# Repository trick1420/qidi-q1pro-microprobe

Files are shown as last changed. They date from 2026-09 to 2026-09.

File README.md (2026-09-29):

# Add a BIQU MicroProbe to a QIDI Q1 Pro and keep the nozzle probe

The Q1 Pro ships with two Z sensors. Most MicroProbe guides replace both. This guide
replaces only the one that fails, and keeps the one that makes the printer
self-calibrating.

Tested on a QIDI Q1 Pro running QIDI's Klipper fork, version `25ee65122`
(firmware V4.4.21), on 2026-09-25.

## What you get

| | Standard MicroProbe guides | This guide |
|---|---|---|
| Bed mesh sensor | MicroProbe | MicroProbe |
| Z=0 sensor | MicroProbe, fixed `z_offset` | Nozzle piezo, measured every print |
| Calibrate `z_offset` after a nozzle change | Yes | No |
| Calibrate `z_offset` after changing the probe mount | Yes | No |
| Detects a blob on the nozzle | No | Yes, as a number in the log |

The difference matters because a fixed `z_offset` is a guess that ages. Change the
nozzle, knock the probe, or leave a bead of plastic on the tip, and the first layer
moves with no warning. The piezo measures the real nozzle-to-plate distance before
every print, so those changes correct themselves.

## Who this is for

You need to be comfortable editing Klipper config files over SSH or through the
Fluidd or Mainsail file editor. You do not need to understand Klipper internals.
Every file and line is named.

Back up these files before you start. Copy them somewhere off the printer.

```
~/klipper_config/printer.cfg
~/klipper_config/gcode_macro.cfg
~/klipper_config/Adaptive_Mesh.cfg
```

## How the Q1 Pro measures Z

The printer has two separate sensors, on two separate pins:

| Sensor | Config section | Pin | Job |
|---|---|---|---|
| Piezo, under the bed | `[smart_effector]` | `U_1:PC1` | Finds Z=0 by touching the plate with the nozzle |
| Inductive, on the toolhead | `[qdprobe]` | `!gpio21` | Probes the bed mesh |

QIDI's fork adds two commands, `QIDI_PROBE_PIN_1` and `QIDI_PROBE_PIN_2`, that switch
which sensor Klipper reads. `PIN_1` selects `[smart_effector]`. `PIN_2` selects
`[qdprobe]`.

`[qdprobe]` depends on a probe object that `[smart_effector]` creates. The two sections
work as a pair. Neither works alone.

Every print runs this sequence:

1. `G28` homes Z roughly, against whichever sensor is selected.
2. `get_zoffset` selects the piezo, touches the plate with the nozzle five times, and
   declares that contact point to be Z = -0.07.
3. `G29` selects the inductive sensor and probes the bed mesh.

Step 2 is what makes the printer self-calibrating. Step 3 is the one that fails, because
an inductive sensor measures the metal under the plate rather than the surface the
plastic lands on.

## Why the usual approach fails

Most guides delete both sections and add a single `[probe]` section for the MicroProbe.
That removes the piezo, so `get_zoffset` no longer exists and Z=0 comes from a fixed
`z_offset` that you calibrate by hand.

On the test machine, hand calibration with the paper method produced `1.530`. The piezo
later measured the same distance as `1.743`. The error of `0.213 mm` put Z=0 almost
double the intended distance above the plate, which ruined every first layer until the
piezo came back.

The single-probe approach has two more problems on this fork:

- `SAVE_CONFIG` does not persist `[probe] z_offset`. Three calibrations wrote `0.000`
  every time. You have to set the value by hand and delete the auto-generated block.
- `G29` normalizes the mesh with `save_meshoffset` and `set_meshoffset`, which assume
  `z_offset` is near zero. Give `[probe]` a real value and the mesh gets corrected twice,
  which drives the nozzle into the plate.

Keeping the piezo avoids all of this. There is nothing to calibrate and nothing to
persist.

## Step 1: wire the probe

Connect the MicroProbe signal wire to the **existing inductive probe connector** on the
toolhead. That connector is `gpio21`. Leave the piezo wiring alone; it runs to the main
board on a different pin and this conversion never touches it.

Connect the MicroProbe control wire to `gpio11`. QIDI's config declares a second hotend
heatsink fan on that pin, as `[heater_fan hotend_fan2]`, but a stock Q1 Pro has only one
heatsink fan fitted. The pin drives nothing, so it is free.

If you added a second hotend fan yourself, `gpio11` is already in use. Find another free
pin on the toolhead board. Do not take the pin from a fan that exists, or you lose half
your hotend cooling and the nozzle jams partway through long prints.

## Step 2: edit printer.cfg

### Replace the probe sections

Find `[qdprobe]` in `~/klipper_config/printer.cfg`. Replace the `[smart_effector]` and
`[qdprobe]` sections with these. Keep everything else in the file as it is.

```ini
[smart_effector]
pin: U_1:PC1
recovery_time: 0
x_offset: 24
y_offset: 10
z_offset: 0.000001
speed: 5
lift_speed: 5
probe_accel: 50
samples: 2
samples_result: submaxmin
sample_retract_dist: 5.0
samples_tolerance: 0.05
samples_tolerance_retries: 5

[qdprobe]
pin: ^!gpio21
z_offset: 0.000001
activate_gcode:
    probe_deploy
    G4 P500
deactivate_gcode:
    probe_stow
deactivate_on_each_sample: false
```

Three changes from the QIDI originals:

- **`x_offset` and `y_offset` change from `17.6` and `4.4` to `24` and `10`.** These
  values live on `[smart_effector]`, but Klipper applies them to whichever sensor is
  active. Only the MicroProbe probes the mesh, so they must be the MicroProbe's offsets.
  Measure your own mount rather than copying these.
- **`[qdprobe] pin` gains a `^`.** The MicroProbe needs the internal pull-up resistor
  that the inductive sensor did not.
- **`[qdprobe]` gains `activate_gcode` and `deactivate_gcode`.** These deploy and retract
  the pin around each probing run. The original QIDI sensors had no moving parts and
  needed neither.

Leave `z_offset: 0.000001` on both sections. That value is deliberate. The piezo sets the
real zero at print time, so Klipper must not apply an offset of its own.

### Remove the unused fan section

Find `[heater_fan hotend_fan2]` in `printer.cfg` and delete it. It claims `gpio11`, and
Klipper refuses to start if two sections claim the same pin.

Skip this step if you fitted a second hotend fan and chose a different pin in step 1.

### Add the control pin

Add this section anywhere in `printer.cfg`:

```ini
[output_pin probe_enable]
pin: gpio11
value: 1
```

`value: 1` means the pin starts in the retracted position. The pin must be retracted
when the piezo probes, or the pin touches the plate before the nozzle does.

### Check the Z endstop

Find `[stepper_z]` and confirm that `position_endstop` is present and not commented out.
Klipper refuses to start without it.

**Keep whatever value your machine already has. Do not copy one from this guide.** The
value differs between firmware versions: `0` on the 2023 release, `-0.2` on the 2025 one,
and `-0.23` on the test machine after an unrelated earlier edit.

Any of them works, because the setting only defines the Z frame between `G28` and
`get_zoffset`, and `get_zoffset` replaces that frame with a real measurement moments
later.

Some MicroProbe guides tell you to comment this line out. That is correct for a single
`[probe]` section and wrong here.

## Step 3: add the deploy macros

Add these to `~/klipper_config/gcode_macro.cfg`:

```ini
[gcode_macro probe_deploy]
gcode:
    SET_PIN PIN=probe_enable VALUE=0

[gcode_macro probe_stow]
gcode:
    SET_PIN PIN=probe_enable VALUE=1
```

Check the direction before you print. Run `probe_deploy` and watch the pin extend, then
`probe_stow` and watch it retract. If the pin moves the wrong way, swap the two `VALUE`
numbers.

## Step 4: leave the QIDI macros alone

Do not modify `PRINT_START`, `homing_override`, `G29`, `get_zoffset`, `set_zoffset`,
`save_zoffset`, `move_subzoffset`, or `test_zoffset`. They work unchanged. They call
`QIDI_PROBE_PIN_1` and `QIDI_PROBE_PIN_2`, which still exist because `[qdprobe]` is still
there.

If a guide told you to delete or comment out any of those macros, restore them from your
backup.

One optional change removes a duplicate homing cycle. `PRINT_START` calls `G28`, and
`G29` then calls `G28` again. To home once per print and still allow `G29` on its own,
wrap the call inside `G29`:

```ini
{% if 'xyz' not in printer.toolhead.homed_axes %}
    G28
{% endif %}
```

## Step 5: adjust the nozzle wipe

`CLEAR_NOZZLE` in `gcode_macro.cfg` wipes the nozzle by moving it left and right across
a brush. The stock travel reaches `X65`, which collides with the MicroProbe.

The factory macro cleans in three phases: fast shallow passes at `X85`, then **nine slow
deep passes to `X65` at `F500`**, then fast passes again. The slow deep passes are what
actually scrub the nozzle. Everything else is a wipe.

`X65` is where the MicroProbe collides, so the deep scrub has to be shortened rather than
removed. Find your own limit by stepping in with the probe stowed:

```
G28
probe_stow
G90
G1 Z35 F900
G1 X97 F15000
G1 Y243 F15000
G1 Y254 F800
G1 X80 F1000
G1 X77 F1000
G1 X74 F1000
```

Stop when the probe is close to the wiper assembly. The test machine reaches **X73**.
Change the `X65` in the deep-scrub passes to your number and leave the rest of the macro
alone.

**Losing that deep scrub is the real cost of this conversion.** Delete it instead of
shortening it, as I did at first, and ooze bends over on the tip instead of shearing off —
no amount of temperature tuning replaces it.

## Step 6: set the mount height

The MicroProbe pin has a fixed travel. On the test machine that travel is `2.36 mm`, and
it divides between two things that both matter:

```
deployed reach + stowed clearance = pin travel
```

- **Deployed reach** is how far the pin hangs below the nozzle when extended. It must
  exceed anything stuck to the nozzle tip, or the nozzle reaches the plate first and the
  probe never fires.
- **Stowed clearance** is how far the pin sits above the nozzle when retracted. It must
  exceed the height of anything already printed, or the pin catches on the part.

Aim for at least `1.0 mm` deployed and at least `0.6 mm` stowed. The final mount on the
test machine measures:

```
deployed reach     1.391 mm
stowed clearance   0.85 mm
pin travel         2.24 mm
```

`stl/microprobe-mount-v6.stl` is that mount. Treat it as a starting point rather than a
drop-in: nozzle length and how far the probe body seats in its clamp both move the result,
and on the test machine reseating the same bracket shifted the reach by 0.14 mm.

Raising the probe in its mount converts deployed reach into stowed clearance, one
millimeter for one millimeter. If your mount clamps the probe body, set the height there
rather than by redesigning the bracket. Clamp position moves the result more than
bracket geometry does.

## Step 7: verify

Run each step and check the result before moving on.

1. **Restart Klipper.** It must report ready with no warnings.

2. **Confirm the switching commands exist.** Send `QIDI_PROBE_PIN_2`, then
   `QIDI_PROBE_PIN_1`. Both return silently. `Unknown command` means `[qdprobe]` did not
   load.

3. **Home the printer.** Send `G28` and watch the pin. It deploys, probes, and retracts.
   Only the MicroProbe runs here.

4. **Measure the nozzle zero.** Heat the bed to 70°C and the nozzle to 150°C, then send
   `get_zoffset`. Stand at the machine. The nozzle descends and touches the plate five
   times. Read the `Result is z=` line in the console.

   That number is the MicroProbe's standoff, measured by the nozzle. Record it. On the
   test machine it is `-1.601`. Five samples should agree within about `0.01 mm`.

5. **Check Z=0 against a gauge block.** Put a gauge block of known height on the plate at
   the centre, then send `G1 X120 Y120 F6000` and `G1 Z<block height> F300`. The nozzle
   touches the top of the block.

   This is the single most valuable check in the process. A feeler gauge tells you how a
   gap feels; a gauge block tells you whether the machine's idea of Z=0 matches the plate
   surface, against a precision reference. On the test machine a 40 mm block confirmed it
   to within a hundredth of a millimetre.

   `get_zoffset` declares the nozzle contact point as `-0.07`. That value compensates for
   how far the nozzle presses into the plate before the piezo registers force, so **Z=0
   lands on the plate surface**, not above it.

6. **Check the stowed clearance.** Send `probe_stow`, return to `Z0`, and slide feeler
   gauges under the **pin**. Subtract `0.07` from whatever fits.

7. **Print something small** and look at the first layer.

After this, the `Result is z=` value appears in `klippy.log` on every print. Watch it. A
drop of more than about `0.1 mm` means something is on the nozzle tip.

## Optional: guard against a bad mesh

An inductive or mechanical probe can misfire and produce a mesh that drives the nozzle
into the plate or lifts it clear of it. On the test machine, one misfire produced a mesh
that lifted the nozzle `0.954 mm` and wasted seven meters of filament before anyone
noticed.

A guard macro reads the mesh after `G29`, compares it against limits, and stops the print
if the numbers are implausible. A healthy mesh on this machine has a range of `0.03` to
`0.17 mm`. The broken one had a range of `1.175 mm`, so the two are easy to tell apart.

See `mesh_guard.cfg` in this repository. Add `[include mesh_guard.cfg]` to `printer.cfg`
above the `#*# <---------------------- SAVE_CONFIG ---------------------->` line, then
add `VALIDATE_MESH` to `PRINT_START` immediately after `G29`.

Anything below that `SAVE_CONFIG` line gets rewritten automatically, and this printer
rewrites it on every print. Config you put there disappears.

## Level the bed with Z_TILT_ADJUST

The Q1 Pro drives its two Z motors independently, so Klipper can correct a left-to-right
tilt mechanically instead of leaving it to the mesh.

```
G28
Z_TILT_ADJUST
```

The stock `[z_tilt] points` work unchanged. `z_tilt` does **not** apply the probe's XY
offsets — unlike `bed_mesh`, it treats `points` as toolhead positions — so the 24 mm
offset doesn't put them out of reach.

On the test machine this found a **0.1 mm tilt across 215 mm** and converged to 0.008 in
one retry. Run `G29` afterwards; levelling changes the bed plane and any existing mesh is
stale.

Once it converges reliably, add it to `PRINT_START` between homing and the clean, so the
mesh is built on a levelled bed:

```
    G28
    Z_TILT_ADJUST
    CLEAR_NOZZLE HOTEND={hotendtemp}
    G29
    VALIDATE_MESH
```

Both motors sit at the same Y, so this corrects left-right tilt only. Front-to-back tilt
stays the mesh's job.

## Optional: fix the purge line

**Check which prime line you actually have first.** QIDI Studio and OrcaSlicer profiles
often draw their own in `machine_start_gcode`, in which case KAMP's `LINE_PURGE` never
runs and none of the settings below do anything. Search your sliced file for
`machine_start_gcode` and see whether it contains `G1 X... E...` moves.

If KAMP does draw your purge: it probes only the area your part occupies, and it draws the
purge line outside that area. The purge therefore prints on ground the printer never
measured, which makes it the least reliable line of the print.

In `~/klipper_config/Adaptive_Mesh.cfg`:

| Line | Setting | Change to |
|---|---|---|
| 24 | `variable_margin_enable` | `True` |
| 25 | `variable_margin_size` | `15` |
| 168 | `variable_distance_to_object_y` | `5` |

The mesh then extends 15 mm past the part, and the purge line moves to 5 mm from it. The
purge lands on measured ground with 10 mm to spare.

Both of the first two settings are required. Line 62 of the same file forces
`margin_size` to `0` whenever `margin_enable` is `False`.

## Troubleshooting

**`Unknown command: QIDI_PROBE_PIN_1`**
`[qdprobe]` is missing or failed to load. Both `[smart_effector]` and `[qdprobe]` must be
present. Neither works alone.

**`Option 'position_endstop' in section 'stepper_z' must be specified`**
Uncomment `position_endstop: -0.23` in `[stepper_z]`.

**`File contains parsing errors`, every line listed**
Your editor indented the pasted config. Klipper requires option lines to start at column
zero. Only the lines inside `activate_gcode` and `deactivate_gcode` are indented.

**The mesh comes out around -1.5 at every point**
`z_offset` has a real value instead of `0.000001`, so the mesh is corrected twice. Set
both `z_offset` values back to `0.000001`.

**The nozzle never reaches the plate during `get_zoffset`**
The pin is deployed when it should be stowed. Check `probe_deploy` and `probe_stow`
directions, and confirm `[output_pin probe_enable]` has `value: 1`.

**`PROBE_CALIBRATE` returns a negative number**
Something below the nozzle touched first: a deployed pin, or a blob of plastic. You do
not need `PROBE_CALIBRATE` with this setup. The piezo replaces it.

**`sudo systemctl` is not permitted**
QIDI blocks `systemctl` in the sudoers file. Restart services through Moonraker instead,
at **Machine > Services** in Fluidd. Moonraker can restart `klipper`, `moonraker`,
`klipper_mcu`, and `webcamd`.

## Reference

Working configuration from the test machine is in `config-backups/`. `gcode_macro-CHANGES.md`
records every change against the stock files, with the reason for each.

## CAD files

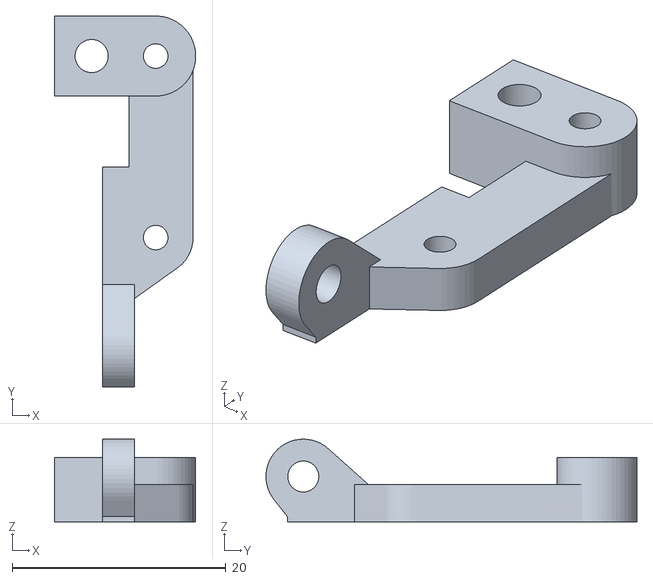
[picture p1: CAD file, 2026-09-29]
stl/microprobe-mount-v6.stl
13.3 x 34.7 x 7.75

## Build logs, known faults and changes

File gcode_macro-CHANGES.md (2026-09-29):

# Change reference

Every change from the stock QIDI Q1 Pro configuration, and the reason for each. The
`README.md` file explains how to make these changes. This file records what they are, so
you can compare against your own machine or undo one of them.

Baseline is the configuration as QIDI shipped it, captured on 2026-09-19 before the
MicroProbe conversion. Current state is 2026-09-25.

Stock and pre-conversion copies of every file are in `config-backups/`.

## printer.cfg

### `[smart_effector]` — the piezo sensor

| Setting | Stock | Now | Why |
|---|---|---|---|
| `x_offset` | `17.6` | `24` | Klipper applies one pair of offsets to whichever sensor is active. Only the MicroProbe probes the mesh, so these must be its offsets. Measure your own mount. |
| `y_offset` | `4.4` | `10` | Same reason. |

`pin: U_1:PC1` and `z_offset: 0.000001` do not change. The piezo wiring is untouched by
this conversion.

### `[qdprobe]` — now the MicroProbe

| Setting | Stock | Now | Why |
|---|---|---|---|
| `pin` | `!gpio21` | `^!gpio21` | The MicroProbe needs the internal pull-up resistor. The inductive sensor did not. |
| `activate_gcode` | absent | `probe_deploy` then `G4 P500` | Extends the pin before probing. The stock sensors had no moving parts. |
| `deactivate_gcode` | absent | `probe_stow` | Retracts the pin afterwards. |
| `deactivate_on_each_sample` | absent | `false` | Deploys once per probing run instead of once per sample. |

`z_offset: 0.000001` does not change, and must not. `[qdprobe]` and `[smart_effector]`
share one probe object, so a real value here gets applied twice and drives the nozzle
into the plate.

### `[heater_fan hotend_fan2]` — removed

Stock declares a second hotend heatsink fan on `gpio11`. A stock Q1 Pro has only one
heatsink fan fitted, so the section drives nothing. Removing it frees `gpio11` for the
MicroProbe control pin, and Klipper refuses to start if two sections claim one pin.

If you added a second hotend fan yourself, keep this section and pick a different pin for
`probe_enable`.

### `[output_pin probe_enable]` — new

```ini
[output_pin probe_enable]
pin: gpio11
value: 1
```

Controls the MicroProbe pin. `value: 1` starts the pin retracted, which the piezo needs.

### `[bed_mesh]`

`vibrate_gcode: Z_DOUDONG` is commented out. `Z_DOUDONG` conditions the piezo sensor
before it measures. The MicroProbe probes the mesh and does not need it.

### `[stepper_z]`

`position_endstop` changed from `-0.2` to `-0.23` on the test machine, by an earlier edit
unrelated to this conversion. The value differs between firmware versions and has no
effect on printing: it sets the Z frame between `G28` and `get_zoffset`, and
`get_zoffset` overwrites that frame a moment later. Keep whatever your machine has.
Klipper refuses to start if the line is missing.

### Includes

`[include mesh_guard.cfg]` added, above the `#*# SAVE_CONFIG` marker. Anything below that
marker is rewritten automatically, on every print.

## gcode_macro.cfg

### New macros

```ini
[gcode_macro probe_deploy]
gcode:
    SET_PIN PIN=probe_enable VALUE=0

[gcode_macro probe_stow]
gcode:
    SET_PIN PIN=probe_enable VALUE=1
```

Swap the two `VALUE` numbers if your pin moves the wrong way.

### `CLEAR_NOZZLE`

| Change | Why |
|---|---|
| Wipe travel `X85` and `X65` becomes `X77` | `X65` collides with the MicroProbe |
| Purge cut from `80 mm` to `30 mm` | Enough to clear ooze on a nozzle that is already clean |
| `G92 E0` then `G1 E-2 F1800` after the purge | Relieves melt-zone pressure. Without it, PETG oozes after the wipe and forms a curl on the tip. |
| `G4 P5000` before the first wipe | Lets the purge blob set so it snaps off rather than smearing |
| First wipe at `180 °C`, second wipe at `140 °C` | Stock waits only for a `20 °C` drop, so it wipes at `230 °C` while PETG still flows, then oozes on the way down with nothing to catch it. The second pass removes that ooze. |

`CLEAR_NOZZLE_PLR` gets the same treatment and an `M107` at the end. Stock leaves the
part fan at full. It runs only when you resume after a power cut.

### `PRINT_START`

Restructured. `CLEAR_NOZZLE` runs before `G29` rather than after `M109`, so the nozzle
cools during meshing instead of making you wait. `VALIDATE_MESH` runs immediately after
`G29`. An optional `SOAK` parameter adds a bed soak in seconds.

### `G29`

The `G28` call is now conditional:

```ini
{% if 'xyz' not in printer.toolhead.homed_axes %}
    G28
{% endif %}
```

`PRINT_START` already homes, so stock homes twice per print. The condition removes the
duplicate and still lets you run `G29` on its own.

### Unchanged

`get_zoffset`, `move_subzoffset`, `set_zoffset`, `save_zoffset`, `test_zoffset`,
`homing_override`, `set_meshoffset`, `save_meshoffset`, and `Z_DOUDONG` are all stock.

Do not delete them. They are the piezo measurement path, and they work unmodified because
`[qdprobe]` still provides `QIDI_PROBE_PIN_1` and `QIDI_PROBE_PIN_2`.

## Adaptive_Mesh.cfg

| Line | Setting | Stock | Now |
|---|---|---|---|
| 24 | `variable_margin_enable` | `False` | `True` |
| 25 | `variable_margin_size` | `5` | `15` |
| 168 | `variable_distance_to_object_y` | `10` | `5` |

KAMP probes only the area your part occupies and draws the purge line outside it, so the
purge prints on ground the printer never measured. These three settings extend the mesh
15 mm past the part and move the purge to 5 mm from it.

Both of the first two are required. Line 62 forces `margin_size` to `0` whenever
`margin_enable` is `False`.

## Z tilt

`Z_TILT_ADJUST` works unchanged and is worth enabling. The stock `[z_tilt] points` need no
edit: `z_tilt` does not apply the probe's XY offsets, unlike `bed_mesh`, so it treats them
as toolhead positions and the 24 mm offset is irrelevant.

On the test machine it found a 0.1 mm left-to-right tilt across 215 mm and converged to
0.008 in one retry. Add it to `PRINT_START` between `G28` and `CLEAR_NOZZLE`.

`[bed_screws]` and `[screws_tilt_adjust]` stay unused. `screws_tilt_adjust` does apply
probe offsets, which puts its front-left screw out of reach, and with `z_tilt` working and
a mesh range under 0.09 there is nothing for manual screw levelling to fix.

## New files

`mesh_guard.cfg` reads the bed mesh after `G29` and stops the print if the numbers are
implausible. A healthy mesh on this machine has a range of `0.03` to `0.17 mm`. One probe
misfire produced a range of `1.175 mm` and a correction that lifted the nozzle `0.954 mm`
off the plate.

Default limits are range `0.80`, peak `0.60`, and step `0.25 mm`. A full-bed mesh
legitimately reaches a peak of about `0.45`, so do not tighten these below `0.5`.

## Measured values from the test machine

Your numbers will differ. These show what a healthy result looks like.

| Value | Reading | Where it comes from |
|---|---|---|
| MicroProbe standoff | `1.391 mm` | `Result is z=` from `get_zoffset`, every print |
| Stowed pin clearance | `0.85 mm` | Feeler gauge under the stowed pin |
| Pin travel | `2.24 mm` | Standoff plus clearance |
| Z=0 accuracy | confirmed | 40 mm gauge block, nozzle touches at `G1 Z40` |
| Bed mesh range | `0.059-0.088 mm` | `MESH CHECK` console line |
| Piezo sample spread | `0.002 mm` | Last four of five samples per run |
| Probe repeatability | `0.005 mm` | `PROBE_ACCURACY`, steady state after two settling probes |

Watch the standoff. It is measured on every print and written to `klippy.log`. A drop of
more than about `0.1 mm` means something is on the nozzle tip.

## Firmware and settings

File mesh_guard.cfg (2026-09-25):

#####################################################################
#  MESH GUARD  -  abort the print if the bed mesh looks implausible
#####################################################################
#
#  WHY THIS EXISTS
#  ---------------
#  On 2026-09-19 at 14:48 the non-contact probe (QIDI_PROBE_PIN_2)
#  misfired during G29. The zero-reference probe returned 2.201
#  instead of its normal ~3.38, and the resulting mesh told the
#  printer to lift the nozzle by up to +0.954 mm across the part.
#  It then extruded 6983 mm of PETG into open air for 66 minutes.
#
#  A broken mesh is trivially distinguishable from a good one:
#
#     time    range   peak    max step    result
#     00:21   0.030   0.023     ~0.02     good
#     00:51   0.157   0.138     ~0.05     good
#     09:44   0.168   0.133     ~0.05     good
#     10:23   0.098   0.089     ~0.04     good
#     17:18   0.135   0.145     ~0.05     good
#     14:48   1.175   0.954      0.62     BROKEN
#
#  The factory full-bed [bed_mesh default] profile reaches
#  range 0.533 / peak 0.449 / step 0.155, so the limits below are
#  set above that to avoid false aborts on whole-plate prints,
#  while still leaving better than 2x margin under the broken run.
#
#  Tighten them once you have a baseline - every run prints its
#  numbers to the console, so after a week you will know your real
#  spread. Adjust live without restarting:
#
#     SET_GCODE_VARIABLE MACRO=VALIDATE_MESH VARIABLE=max_range VALUE=0.5
#
#
#  INSTALL
#  -------
#  1. Back up printer.cfg first:
#       cp ~/klipper_config/printer.cfg ~/klipper_config/printer.cfg.bak
#
#  2. Keep this as its own file and pull it in from printer.cfg:
#       [include mesh_guard.cfg]
#     Better than pasting the macros inline, because this machine runs
#     SAVE_CONFIG on every print and anything living below the
#       #*# <---------------------- SAVE_CONFIG ---------------------->
#     marker gets rewritten. Note the INCLUDE LINE ITSELF still has to
#     sit above that marker or it will be wiped on the next save.
#
#  3. In [gcode_macro PRINT_START], add VALIDATE_MESH directly after
#     G29 so it runs before the hotend comes up to print temperature:
#
#         G28
#         CLEAR_NOZZLE HOTEND={hotendtemp}
#         M190 S{bedtemp}
#         G29
#         VALIDATE_MESH          <-- add this line
#         G0 Z50 F600
#         ...
#
#  4. RESTART, then run a print and confirm you see the
#     "MESH CHECK" line in the console.
#
#  TEST IT before trusting it - drop max_range to something
#  deliberately tiny (SET_GCODE_VARIABLE ... VALUE=0.01), start a
#  print, and confirm it aborts cleanly at the right moment. Then
#  put the limit back.
#
#####################################################################


[gcode_macro VALIDATE_MESH]
description: Sanity-check the active bed mesh; abort the print if the probe misfired
variable_max_range: 0.80    # max allowed (highest - lowest) across the mesh, mm
variable_max_abs:   0.60    # max allowed magnitude of any single point, mm
variable_max_step:  0.25    # max allowed jump between neighbouring points, mm
gcode:
    {% set bm = printer.bed_mesh %}
    {% set pm = bm.probed_matrix %}
    {% set m  = pm if (pm|length > 0 and pm[0]|length > 0) else bm.mesh_matrix %}

    {% if bm.profile_name == "" or m|length == 0 or m[0]|length == 0 %}
        { action_respond_info("MESH CHECK: no active mesh after G29") }
        _MESH_GUARD_ABORT
        _MESH_GUARD_HALT
    {% else %}
        {% set zs = [] %}
        {% for row in m %}{% for z in row %}{% set _ = zs.append(z) %}{% endfor %}{% endfor %}
        {% set lo   = zs|min %}
        {% set hi   = zs|max %}
        {% set span = hi - lo %}
        {% set peak = [hi|abs, lo|abs]|max %}

        # largest jump between adjacent points, along rows then columns.
        # A real bed is smooth; a misfiring probe is not.
        {% set steps = [] %}
        {% for row in m %}
            {% for i in range(row|length - 1) %}
                {% set _ = steps.append((row[i+1] - row[i])|abs) %}
            {% endfor %}
        {% endfor %}
        {% for r in range(m|length - 1) %}
            {% for c in range(m[r]|length) %}
                {% set _ = steps.append((m[r+1][c] - m[r][c])|abs) %}
            {% endfor %}
        {% endfor %}
        {% set step = steps|max if steps|length > 0 else 0.0 %}

        { action_respond_info(
            "MESH CHECK  %dx%d pts  min=%.3f max=%.3f | range=%.3f/%.2f  peak=%.3f/%.2f  step=%.3f/%.2f"
            % (m|length, m[0]|length, lo, hi,
               span, max_range, peak, max_abs, step, max_step)) }

        {% if span > max_range or peak > max_abs or step > max_step %}
            { action_respond_info("MESH CHECK FAILED - see limits above") }
            _MESH_GUARD_ABORT
            _MESH_GUARD_HALT
        {% endif %}
    {% endif %}


# Runs first: makes the machine safe.
#
# NOTE: do NOT call CANCEL_PRINT from here. CANCEL_PRINT ends with
# SDCARD_RESET_FILE, and Klipper refuses that command while the gcode
# calling it is itself being fed from the SD file - which is exactly
# where we are, since VALIDATE_MESH runs inside PRINT_START. You get
# "!! SDCARD_RESET_FILE cannot be run from the sdcard" instead.
#
# So we do the cleanup by hand and let _MESH_GUARD_HALT stop the file.
# The job is left halted rather than cancelled; press Cancel in
# Fluidd/Mainsail to clear it. That is deliberate - it makes you
# acknowledge the abort instead of it disappearing quietly.
[gcode_macro _MESH_GUARD_ABORT]
description: Safe shutdown after a failed mesh check
gcode:
    M117 MESH CHECK FAILED
    { action_respond_info(
        "MESH GUARD: bed mesh failed validation - the probe almost certainly "
        "misfired. Aborting now instead of printing into thin air.\n"
        "Re-run G28 then G29 and check the MESH CHECK numbers. If it repeats, "
        "inspect the probe connector at the toolhead, the cable through the "
        "drag chain, and the sensor face for debris.") }
    TURN_OFF_HEATERS
    M104 S0
    M140 S0
    M141 S0
    M106 P0 S0
    M106 P2 S0
    M106 P3 S0
    G90
    {% if printer.gcode_move.position.z < 150 %}
        G1 Z150 F480
    {% endif %}
    G1 X0 Y0 F7800
    M400
    BEEP I=4 DUR=300


# Runs second: raises a hard error so the REST of PRINT_START
# (M109, fans, etc.) never executes. This has to be a separate macro
# because action_raise_error fires at template-render time - if it
# were in VALIDATE_MESH, none of the cleanup above would ever run.
[gcode_macro _MESH_GUARD_HALT]
description: Hard-stop the remainder of PRINT_START after a failed mesh check
gcode:
    # Keep this SHORT. It surfaces once per level of the macro call
    # stack as the error unwinds (HALT -> VALIDATE_MESH -> PRINT_START),
    # so you see it about three times. The detail is printed once by
    # _MESH_GUARD_ABORT just above.
    { action_raise_error("MESH GUARD: mesh failed validation - print halted.") }

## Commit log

2026-09-25 Document MicroProbe conversion that keeps the QIDI piezo probe
    Add a how-to for fitting a BIQU MicroProbe to a QIDI Q1 Pro while keeping
    the factory piezo sensor for Z=0. The MicroProbe replaces only the inductive
    bed-mesh sensor, so the printer keeps measuring nozzle-to-plate distance on
    every print and needs no z_offset calibration.
    Include the working config, backups of the stock and pre-conversion files,
    and a mesh validation macro that halts a print when the probe misfires.
    [mesh_guard.cfg]
2026-09-25 Rewrite change reference against the piezo architecture
    The previous version documented the single [probe] approach, which this
    conversion abandoned. It contradicted the README and would have sent a
    reader down the wrong path.
2026-09-25 Correct the hotend fan claim and add the missing removal step
    A stock Q1 Pro has one hotend heatsink fan. The config declares a second
    on gpio11, but no fan is fitted, which is why the pin is free. The previous
    text told readers to verify by watching two fans spin, and only one exists.
    Removing [heater_fan hotend_fan2] was also missing from the steps. Klipper
    refuses to start while that section and [output_pin probe_enable] both
    claim gpio11.
2026-09-25 Stop readers copying a machine-specific position_endstop
    The value differs by firmware version: 0 on the 2023 release, -0.2 on the
    2025 one, -0.23 on the test machine. The guide showed -0.23 in a code block,
    which reads as a value to copy. It only sets the Z frame between G28 and
    get_zoffset, so any value works, but it should stay whatever the reader's
    machine already has.
2026-09-29 Add the final mount STL, document Z tilt, correct two errors
    Publish microprobe-mount-v6.stl, the mount that measures 1.391 mm reach and
    0.85 mm stowed clearance.
    Correct two mistakes in the guide. Z_TILT_ADJUST does not apply the probe's
    XY offsets the way bed_mesh does, so the stock points work and the section
    claiming otherwise was wrong; it now documents Z tilt as a step, having
    found and corrected a 0.1 mm tilt on the test machine. The purge section
    assumed KAMP draws the prime line, but QIDI Studio and OrcaSlicer profiles
    usually draw their own in machine_start_gcode.
    Replace the Z=0 feeler check with a gauge block, which measures against a
    precision reference instead of feel. Docume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
    [microprobe-mount-v6.stl]
